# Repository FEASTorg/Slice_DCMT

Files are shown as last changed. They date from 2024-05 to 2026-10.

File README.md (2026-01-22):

# DC Motor Driver IC Carrier

DC Motor Driver IC Carrier Slice for BREAD.

## Introduction

[Short introduction on the project.]

## Usage

[Explain how to use the project. Include examples and screenshots if applicable.]

## Documentation

Please refer to the [docs](/docs) for more info.

---

<div align="center">
  <p>
    
    
  </p>
</div>

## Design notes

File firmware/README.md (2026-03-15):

# DCMT Firmware Profiles

This firmware separates three concerns:

1. Hardware generation (`DCMT_HW_GEN`)
- selects pin/electrical mapping only.

2. MCU performance profile
- derived from board target by default.
- classic Nano (AVR): speed loop disabled by default.
- Nano Every (megaAVR): speed loop enabled by default.

3. I2C address (`I2C_ADR`)
- independent from generation and board.
- override with `-DI2C_ADR=<addr>`.

## Environment Matrix

- `gen1_nano`
- `gen2_nano`
- `gen1_nanoevery`
- `gen2_nanoevery`

All environments support:

- open-loop
- closed-loop position

Speed closed-loop is controlled by `DCMT_ENABLE_SPEED_LOOP`.
Default behavior is board-dependent (see above), and can be overridden via build flag.

## Closed-Loop Backend

The runtime uses:

- `DCMotorServo` for closed-loop position control
- `DCMotorTacho` for cascaded closed-loop speed control

Current defaults mirror archive-proven values:

- `MOTOR1_CPR = 798`
- `MOTOR2_CPR = 798`
- outer PID defaults: `0.15 / 0.01 / 0.01`
- inner PID defaults: `0.15 / 0.01 / 0.01`
- servo PWM skip: `15`
- servo max PWM: `150`
- servo accuracy: `10`
- tacho interval: `5 ms`

Speed commands/capability are only available when `DCMT_ENABLE_SPEED_LOOP=1`.

## Capability Mapping (`GET_CAPS`)

- Level 2: baseline + closed-position + PID tuning
- Level 3: Level 2 + closed-speed

Controllers should gate behavior by capability flags, not by generation labels.

## References

- Arduino Nano: https://store.arduino.cc/products/arduino-nano
- Arduino Nano Every: https://store.arduino.cc/products/nano-every
- Nano Every docs: https://docs.arduino.cc/hardware/nano-every

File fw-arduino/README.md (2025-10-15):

# Firmware

This directory contains the firmware for the DC Motorized Translation (DCMT) stage. There are three versions of the firmware available:

1. **DCMT-old**: This is the original firmware version used in earlier iterations of the DCMT stage. It provides basic functionality for controlling the motorized stage.

2. **DCMT-open-control**: This version of the firmware allows for open-loop control of the DCMT stage. It provides improved performance and additional features compared to the old version.

3. **DCMT-closed-control**: This is the most advanced version of the firmware, offering closed-loop control for enhanced precision and reliability. It includes features such as position feedback and error correction.

## Development

Always ensure you update the version number in `config.h` when making changes to the firmware and update it's changelog. This helps in tracking different versions and ensuring compatibility with other components of the system.

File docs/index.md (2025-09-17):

---
title: "Slice DCMT Documentation"
description: "Overview and entry page for Slice DCMT project documentation."
nav_exclude: true
---

Welcome to the Slice DCMT project documentation.

## Board Renders

<figure style="display:inline-block; text-align:center; margin:10px;">
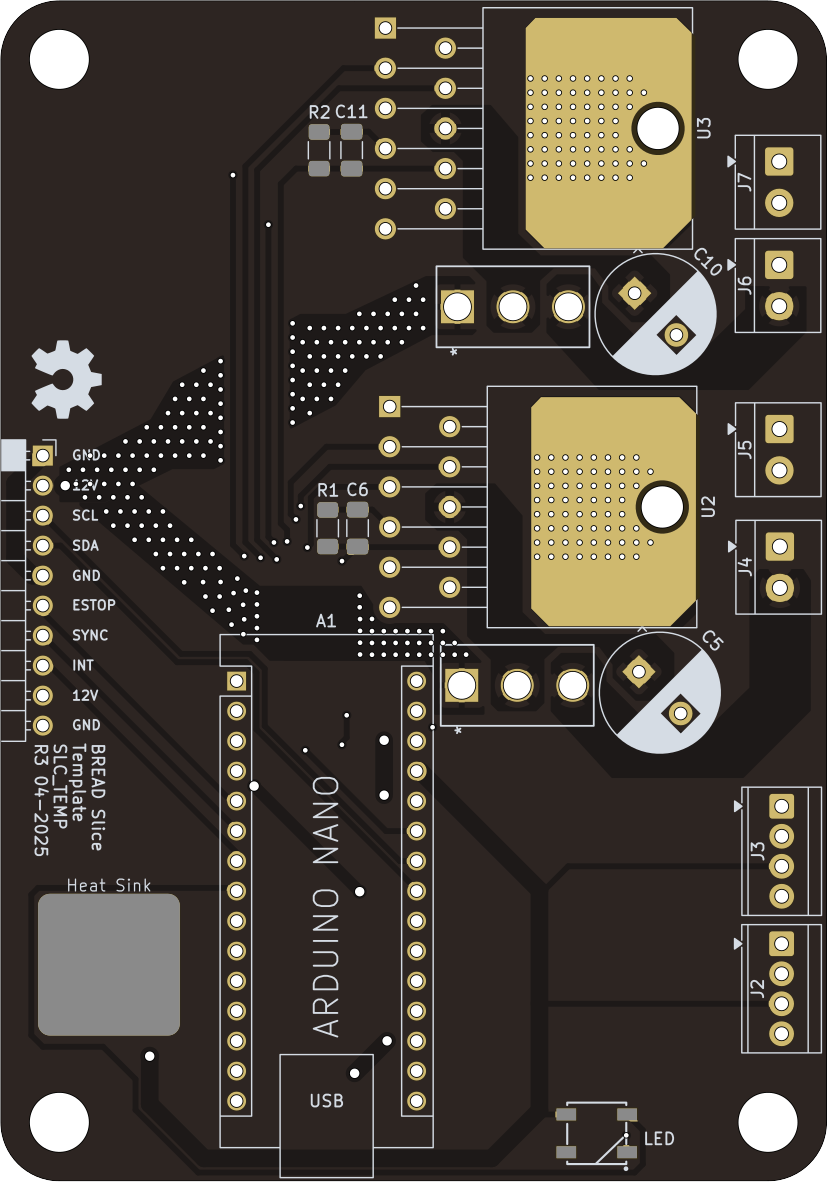
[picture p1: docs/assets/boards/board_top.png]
Board Top
  
  <figcaption>Top</figcaption>
</figure>

<figure style="display:inline-block; text-align:center; margin:10px;">
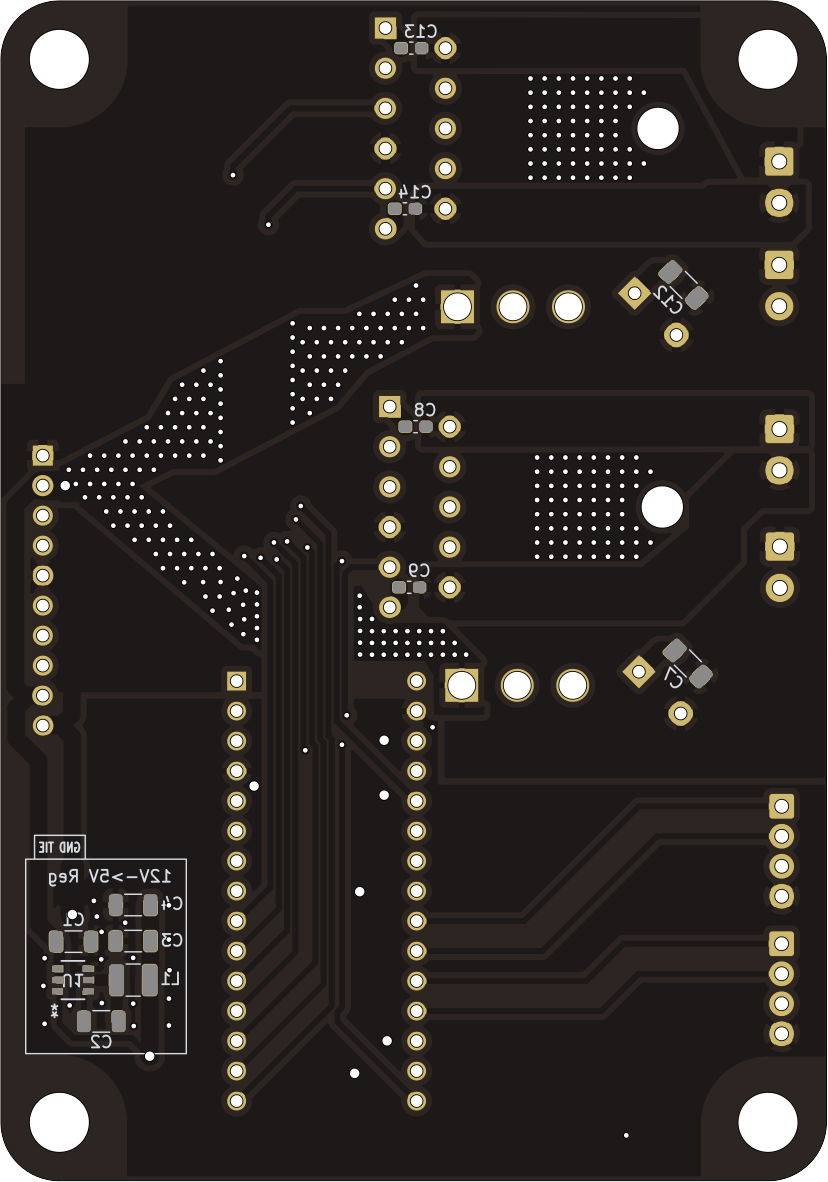
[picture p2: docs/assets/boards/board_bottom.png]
Board Bottom
  
  <figcaption>Bottom</figcaption>
</figure>

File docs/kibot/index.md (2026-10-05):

---
title: "KiBot Outputs"
description: "Index for KiBot-generated PCB artifacts."
layout: "page"
---

These are the docs & KiBot Outputs for Slice DCMT

The following files were generated from the latest PCB build:

- [Schematic.pdf](./Schematic.pdf)
- [PCB.pdf](./PCB.pdf)
- [kibot.log](./kibot.log)
- [BREAD_Slice-bom.html](./BREAD_Slice-bom.html)
- [BREAD_Slice-ibom.html](./BREAD_Slice-ibom.html)

_Last updated automatically on 2026-10-05 at 21:38:37 UTC by KiBot via GitHub Actions._

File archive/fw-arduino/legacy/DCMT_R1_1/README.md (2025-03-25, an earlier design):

# RLHT R1.1 Firmware Docs

Notes on the firmware for dc motor controller slice.

## Serial Command Usage

Send commands via serial using the following formats:

- **Mode Switch (`M` Command):**  
  Format: `M,<mode>`  
  Example: `M,0` (switches to CONTROL mode), `M,1` (switches to WRITE mode)

- **Motor Update (`W` Command):**  
  Format: `W,<motorSelect>,<speedSelect>`  
  Example: `W,1,100` (sets motor 1 speed to 100%), `W,2,-50` (sets motor 2 speed to 50% in reverse)

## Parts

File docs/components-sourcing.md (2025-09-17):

---
title: "Components Sourcing"
description: "Notes and vendor links for sourcing driver ICs and parts."
---

## Driver Options

- LMD18200
  - 3A, 55V H-Bridge
  - [Product page (LMD18200) — Texas Instruments](https://www.ti.com/product/LMD18200)
  - $23.14 (TO-220-11 Formed Leads) on [DigiKey](https://www.digikey.ca/en/products/detail/texas-instruments/LMD18200T-NOPB/148219)
- DRV8874
  - 40-V, 6-A H-bridge motor driver with integrated current sensing feedback
  - [Product page (DRV8874) — Texas Instruments](https://www.ti.com/product/DRV8874)
  - $2.42 (16-HTSSOP) on [DigiKey](https://www.digikey.ca/en/products/detail/texas-instruments/DRV8874PWPR/11502339)
- DRV8256
  - 50-V, 8-A H-bridge motor drivers with integrated current sense and smart tune technology
  - [Product page (DRV8256) — Texas Instruments](https://www.ti.com/product/DRV8256)
  - $3.50 (24-VQFN (4x4)) on [DigiKey](https://www.digikey.ca/en/products/detail/texas-instruments/DRV8256ERGER/13627083)
  - $3.81 (28-HTSSOP) on [DigiKey](https://www.digikey.ca/en/products/detail/texas-instruments/DRV8256EPWPR/15856968)
- DRV8873
  - 40-V, 10-A H-bridge motor driver with integrated current sensing & current sense feedback
  - [Product page (DRV8873) — Texas Instruments](https://www.ti.com/product/DRV8873)
  - $3.36 (24-HTSSOP (Hardwired)) on [DigiKey](https://www.digikey.ca/en/products/detail/texas-instruments/DRV8873HPWPR/9861442)
  - $3.62 (24-HTSSOP (SPI)) on [DigiKey](https://www.digikey.ca/en/products/detail/texas-instruments/DRV8873SPWPR/9861443)
- DRV8876
  - 40-V, 3.5-A H-bridge motor driver with integrated current sensing & current-sense feedback
  - [Product page (DRV8876) — Texas Instruments](https://www.ti.com/product/DRV8876)
  - $1.74 (16-VQFN (3x3)) on [DigiKey](https://www.digikey.ca/en/products/detail/texas-instruments/DRV8876RGTR/11308784)
  - $1.72 (16-HTSSOP) on [DigiKey](https://www.digikey.ca/en/products/detail/texas-instruments/DRV8876PWPR/10270191)
- DRV8251A
  - 50-V, 4.1-A H-bridge motor driver with integrated current regulation & current-sense feedback
  - [Product page (DRV8251A) — Texas Instruments](https://www.ti.com/product/DRV8251A)
  - $1.78 (8-PowerSOIC) on [DigiKey](https://www.digikey.ca/en/products/detail/texas-instruments/DRV8251ADDAR/16182453) (DRV8251ADDAR)
- DRV8231A
  - 35-V, 3.7-A H-bridge motor driver with integrated current regulation & current-sense feedback
  - [Product page (DRV8231A) — Texas Instruments](https://www.ti.com/product/DRV8231A)
  - $1.28 (8-WSON (2x2)) on [DigiKey](https://www.digikey.ca/en/products/detail/texas-instruments/DRV8231ADSGR/15853799)
  - $1.30 (8-PowerSOIC) on [DigiKey](https://www.digikey.ca/en/products/detail/texas-instruments/DRV8231ADDAR/16184255)

## Parts dump

- SPDT switches
  - 5 A: [e-switch 500SSP1S2M2QEA on DigiKey](https://www.digikey.ca/en/products/detail/e-switch/500SSP1S2M2QEA/1803993)
  - 6 A: [C&K 1101M2S3CQE2 on DigiKey](https://www.digikey.ca/en/products/detail/c-k/1101M2S3CQE2/67042)
- THT capacitors
  - 220 µF, 50 V aluminum electrolytic radial can, 42 mΩ @ 100 kHz, 4000 hrs @ 105 °C
  - [Kemet ESY227M050AH2AA on DigiKey](https://www.digikey.ca/en/products/detail/kemet/ESY227M050AH2AA/2712529)

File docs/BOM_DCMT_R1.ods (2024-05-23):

References | Value | Footprint | Quantity | URL
C6, C8, C9, C10, C11, C12 | 10 nF | C_1206_3216Metric_Pad1.33x1.80mm_HandSolder | 6 | https://www.digikey.ca/en/products/detail/walsin-technology-corporation/1206B103J500CT/9355096
C1, C5, C7 | 22uF | C_1206_3216Metric | 3 | https://www.digikey.ca/en/products/detail/samsung-electro-mechanics/CL31A226KAHNNNE/3888705
C2, C3 | 10uF_t | C_1206_3216Metric | 2 | https://www.digikey.ca/en/products/detail/yageo/cc1206kkx5r8bb106/2833631
C4 | 100nF | C_1206_3216Metric | 1 | https://www.digikey.ca/en/products/detail/samsung-electro-mechanics/CL31B104KBCNNNC/3886675
R1, R2 | 4.42 k | R_1206_3216Metric_Pad1.30x1.75mm_HandSolder | 2 | https://www.digikey.ca/en/products/detail/yageo/RC1206FR-074K42L/728878
L1 | 4.7uH | L_1210_3225Metric | 1 | https://www.digikey.ca/en/products/detail/tdk-corporation/BCL322520RT-4R7M-D/15849704
D2 | WS2812B_5050 | WS2812-5050-4PIN | 1 | https://www.digikey.ca/en/products/detail/sparkfun-electronics/COM-16347/11630204
U1, U3 | LMD18200 | TO-220-11_P3.4x5.08mm_StaggerOdd_Lead4.85mm_Vertical | 2 | https://www.digikey.ca/en/products/detail/texas-instruments/LMD18200T/3701191
U2 | AP63205WU-7 | TSOT-23-6 | 1 | https://www.digikey.ca/en/products/detail/diodes-incorporated/AP63205WU-7/9858424
SW1, SW2 | SW_SPDT | L102011MS02Q | 2 | https://www.digikey.ca/en/products/detail/c-k/L102011MS02Q/484143
A1 | Arduino_Nano_v3.x | Arduino_Nano | 1 | https://www.amazon.ca/ELEGOO-Arduino-ATmega328P-Without-Compatible/dp/B0713XK923
HS1 | Heatsink_Pad (optional) | Thermal Pad | 1 | https://www.digikey.ca/en/products/detail/assmann-wsw-components/V2017B/3511410
J10, J11, J13, J15, J16, J17 | Term_PressFit_Phoenix_Contact | Term_PressFit_5mm_H_PC | 2 (4x) | https://www.digikey.ca/en/products/detail/phoenix-contact/1990999/3605138
J12, J14 | Term_PressFit_Phoenix_Contact | Term_PressFit_5mm_H_ENDCAP_PC
J2, J3, J4, J5, J7, J8, J9 | Term_PressFit_Phoenix_Contact | Term_PressFit_3.5mm_H_PC | 1 (8x) | https://www.digikey.ca/en/products/detail/phoenix-contact/1990795/3605145
J6 | Term_PressFit_Phoenix_Contact | Term_PressFit_3.5mm_H_ENDCAP_PC | 1
J1 | Conn_01x10_Female | PinSocket_1x10_P2.54mm_Horizontal | 1 | https://www.digikey.ca/en/products/detail/sullins-connector-solutions/PPTC101LGBN-RC/775904
J18 | I2C_01x04 | JST_SH_SM04B-SRSS-TB_1x04-1MP_P1.00mm_Horizontal | 1 | https://www.digikey.ca/en/products/detail/jst-sales-america-inc/SM04B-SRSS-TB/926710

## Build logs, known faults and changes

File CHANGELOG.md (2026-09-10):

# Changelog

All notable changes to Slice DCMT are documented here.

This project did not use formal release tags through most of its history, so this changelog is organized by dated development eras rather than semantic-version releases.

## [Unreleased]

### Fixed

- **The Docs Pipeline runs again.** `hardware/.history` was committed as a
  gitlink (mode `160000`) with no `.gitmodules` entry, so `actions/checkout`
  failed with `fatal: No url found for submodule path 'hardware/.history'`
  and all three KiBot jobs — Fab, ERC and DRC — died before running, taking
  the index and Pages deploy with them. The directory is KiCad 10's own
  Local History: KiCad runs `git_repository_init` on `<project>/.history`,
  so committing it records a gitlink to a repository this one knows nothing
  about. It is recreated on every project open, on every machine, which is
  why the ignore rule matters rather than a one-time cleanup.

- **Corrected the G1 pin map in `docs/hardware-revisions.md`.** D8 and D12
  were listed as unused; G1 routes `/THRM2` to D8 and `/THRM1` to D12, on
  Nano pads 11 and 15. D13 is the unused one. The whole table has since been
  regenerated from the board files. No firmware impact — the thermal flags
  are not read anywhere in `firmware/`.

- **The status LED no longer drives motor 1's direction line on gen1** (#15).
  `LED_PIN` sits in the shared "General BREAD" block and is inherited by every
  slice whether or not that board populates an LED — `Slice_RLHT` carries the
  identical line. Gen1 DCMT boards do not populate it, and gen1 additionally maps
  `MOTOR1_DIR` to the same MCU pin (5), so FastLED's NeoPixel bit-banging wrote
  onto motor 1's direction line. Motor 1 is the sample pump on `dcmt0` and a
  dosing pump on `dcmt1`; the impeller is motor 2 and is unaffected.

  `Slice_RLHT` encoded the same fact as `RLHT_HAS_STATUS_LED` when the gen1/gen2
  split was done (2026-03-09); DCMT's split landed the same day without it. This
  adds the mirror-image `DCMT_HAS_STATUS_LED`.

  The worst case was the e-stop path rather than boot. `LMD18200::brake()` never
  touches DIR and is idempotent, and a held e-stop or watchdog trip calls only
  `brake()` — so a direction bit scrambled by `FastLED.show()` during an e-stop
  **persisted until the next `write()`**, rather than being corrected on the next
  control cycle. (At boot the LED write is overwritten microseconds later by
  `motor1Driver.begin()`/`write(0)`, so the boot case was benign.)

  `LED_PIN` itself is now defined only on boards that have the LED, so a future
  call site that reaches for it on gen1 is a build failure rather than a silent
  repeat of this bug.

  **Gen1 boards no longer have a local e-stop indicator.** The red/green LED was
  the only unconditional at-the-bench signal; `SLICE_DEBUG` serial output is
  compiled out by default. E-stop state remains readable over the bus via
  `reply_get_state`.

### Added

- Added a curated root changelog derived from the full repository and history review.

### Changed

- **Archived board directories now name their generation**:
  `archive/hw_archive/g1-2021-06-08-mtu/` and
  `archive/hw_archive/g2-2024-02-13-finn/`. The dates are the boards' own;
  the G2 one is marked on the JLC silkscreen. Directory names were the only
  record of which archived project was which generation, and they did not
  say, which is what made a G1 board in service look like the board in
  `hardware/`.

- **Removed the redundant second G1 archive** (`archive/hw_archive/2023-12-13/`).
  Converting both projects to a common format showed it was a KiCad 6
  re-save rather than a second fabrication run: identical pad-to-net map
  (112 pads), identical copper geometry (198 tracks, arcs and vias) and a
  byte-identical exported netlist. Recoverable from git history.

- Updated active firmware metadata to reference CRUMBS `0.12.4` and
  `bread-crumbs-contracts` `0.4.3`.

### Fixed

- Fixed intermittent CRUMBS query failures (all-`0xFF` non-responses and
  CRC-corrupt replies, ~1-47% of reads from a Raspberry Pi master) caused by
  the whole-struct interrupt-masked snapshot in `motorControlLogic()`
  introduced by the 2026-05-12 shared-state hardening. The ~72-byte copy
  masked interrupts for ~20-36 µs every loop iteration, delaying TWI ISR
  entry at the SLA+R boundary; the resulting clock stretch is mishandled by
  the Pi's I2C controller. The snapshot now copies only the scalar control
  inputs in a short window, with PID tunings fetched separately only in
  closed-loop modes. Verified on hardware: 0/1050 failed queries versus
  26/1050 on a same-bus stock control board. (#3)

## [2026-05-12] Firmware Runtime Hardening

### Added

- Added a 1 second AVR watchdog to the active PlatformIO firmware.

### Changed

- Reworked shared state access so firmware snapshots and commits are protected with interrupt guards.
- Replaced Arduino `String`-based serial command parsing with a fixed static command buffer.

### Fixed

- Fixed serial command trimming so empty strings are handled safely.
- Added portability fixes for megaAVR/Nano Every targets.
- Reduced runtime heap-fragmentation risk in serial command handling.

## [2026-04-01 to 2026-04-20] Dependency And Organization Cleanup

### Changed

- Bumped active firmware dependencies to CRUMBS `0.12.0` and `bread-crumbs-contracts` `0.4.1`.
- Updated repository, docs, and workflow references from `FEASTorg` casing to `feastorg`.
- Refreshed generated KiBot documentation output after the organization rename.

## [2026-03-08 to 2026-03-18] PlatformIO Firmware Modernization

### Added

- Added active PlatformIO build environments for `gen1_nano`, `gen2_nano`, `gen1_nanoevery`, and `gen2_nanoevery`.
- Added Nano Every support with board-dependent speed-loop defaults.
- Added optional closed-loop speed support through `DCMotorTacho` for capable builds.
- Added closed-loop position support through `DCMotorServo`.
- Added bitwise capability replies for baseline, closed-position, PID tuning, and optional closed-speed support.
- Added build-flag controlled I2C address selection.
- Added build-flag controlled CRUMBS/debug output.
- Added archive preservation for the former Arduino and PlatformIO firmware generations.
- Added `.gitattributes` for cross-platform file normalization.

### Changed

- Converted active firmware to newer CRUMBS and published BREAD/DCMT contracts.
- Moved active firmware away from vendored CRUMBS and LMD18200 code toward published package dependencies.
- Separated hardware generation, MCU target/profile, control capability, and I2C address selection.
- Made setpoints and PID tunings preloadable independent of the active control mode.
- Made module version ownership come from the published contract rather than a duplicate local definition.
- Reworked CRUMBS state replies to use a fixed payload layout across modes.
- Reorganized active and archived firmware directories.

### Fixed

- Restored proper closed-loop position behavior through the DCMotorServo backend.
- Improved e-stop handling with debounce and internal pull-up input behavior.
- Prevented repeated PID reapplication when tuning values have not changed.
- Removed setpoint gating that prevented controllers from preloading values.
- Added explicit invalid-data sentinels for unsupported or inactive state fields.
- Inset encoder range reporting to avoid false sentinel-value collisions.
- Fixed servo function declaration ordering.
- Reduced serial string-handling fragility.

## [2026-01-22 to 2026-02-01] Legacy Firmware Organization And Template Review

### Added

- Added older generation firmware scripts for historical context.

### Changed

- Reorganized firmware layout before the March 2026 active firmware rewrite.
- Reviewed and revised the repo against the current project template and KMLib-era conventions.
- Refreshed generated KiBot index and board render outputs through CI reruns.

## [2025-10-15 to 2025-10-22] Firmware Versioning And Split

### Added

- Added explicit firmware versioning.
- Added changelog files for generation-specific Arduino firmware snapshots.

### Changed

- Updated firmware for different board revisions.
- Updated uploaded/default address tracking.
- Renamed firmware folders/files to better match hardware revisions.
- Split firmware organization into Arduino and PlatformIO tracks.

## [2025-09-05 to 2025-09-24] Docs, KiBot, And GitHub Pages Automation

### Added

- Added GitHub Actions automation to build KiBot outputs and publish them to GitHub Pages.
- Added a docs site structure with index, component sourcing, architecture, testing, changelog, TODO, and KiBot output pages.
- Added KiBot output indexing for generated artifacts.
- Added top and bottom PCB render assets for the docs site.
- Added interactive HTML BOM publishing.
- Added KiBot 3D model caching and retry behavior for more reliable CI runs.

### Changed

- Switched docs to Just the Docs/Jekyll configuration.
- Moved KiBot site configuration under `docs/kibot/`.
- Centralized hardware/docs publishing through reusable infrastructure workflows, first under `slice-infra` and then under `bread-infra`.
- Renamed workflow roles toward the current `docs-pipeline` and `publish-kibot` flow.
- Moved component sourcing notes into their own document.

### Fixed

- Fixed Pages deployment ordering so published pages align with the generated KiBot index commit.
- Fixed artifact download, staging, push/rebase, and generated-index behavior across the docs pipeline.
- Fixed Jekyll/front matter issues that affected navigation and page rendering.
- Fixed iBoM and artifact glob handling so all matching KiBot outputs are published.
- Fixed PCB render generation, including true bottom-view rendering.
- Removed brittle yq handling in favor of native Python parsing in the automation path.
- Cleaned up temporary debug and generated-index workflow churn after the pipeline stabilized.

## [2025-05-06 to 2025-05-19] Hardware Revision And First KiBot Workflow

### Added

- Added the main current KiCad hardware source under `hardware/`.
- Added `motor_driver_lmd18500.kicad_sch` for the motor driver sheet.
- Added KiBot configuration for schematic PDF, PCB PDF, BOM, iBoM, Gerbers, drill files, position files, and board renders.
- Added a hardware Makefile with KiBot targets for ERC, DRC, schematic fabrication output, and PCB fabrication output.
- Added early GitHub Actions workflow support for KiBot runs.
- Added notes for alternative future motor-driver parts.

### Changed

- Consolidated newer hardware work from temporary/new folders into the primary `hardware/` directory.
- Moved historical hardware snapshots into archive locations.
- Updated the PCB around electrolytic capacitance, filled zones, thermal/tab layout, and 12 V routing constraints.
- Moved the KiBot config under `hardware/`.

### Fixed

- Corrected initial KiBot workflow naming, paths, root references, Makefile location, and config placement.

## [2025-02-20 to 2025-04-19] Hardware Archive And Firmware Control Expansion

### Added

- Added historical PCB snapshots from 2021 and 2023.
- Added braking support to the firmware lineage.
- Added newer DCMT firmware sketches and preserved older sketches under legacy paths.
- Added LMD18200 library usage to the firmware.
- Added DCMT-specific request/message handlers, serial commands, and serial output helpers.
- Added early position and speed controller support.
- Added a new hardware design branch before it was later consolidated into the main hardware folder.

### Changed

- Reorganized firmware into active and legacy sketch directories.
- Renamed RLHT-oriented handler naming to DCMT-specific naming.
- Evolved firmware from basic motor output toward position/speed control behavior.

### Fixed

- Removed temporary KiCad autosave and lock artifacts that were introduced during early hardware editing.

## [2024-05-23 to 2024-09-10] Project Foundation

### Added

- Added the initial KiCad hardware project for the DC Motor Driver IC Carrier Slice.
- Added the initial license, `.gitignore`, README, BOM material, and generated fabrication outputs.
- Added `BOM_DCMT_R1.ods` as the early BOM artifact.
- Added the first firmware seed sketch under `firmware/`.

### Changed

- Refreshed the initial KiCad board and schematic after the first repository seed.
- Simplified the README as the repo shifted from hardware-only scaffolding toward a combined hardware/firmware project.

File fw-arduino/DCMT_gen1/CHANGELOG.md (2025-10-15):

# DCMT (Old) Changelog

## Version 1.0.0

- Initial release of the DCMT (Old) firmware.

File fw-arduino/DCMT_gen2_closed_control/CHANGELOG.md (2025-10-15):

# DCMT Closed Control Changelog

## Version 1.0.0

- Initial release of the DCMT Closed Control firmware.

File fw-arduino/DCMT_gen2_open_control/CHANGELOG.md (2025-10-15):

# DCMT Open Control Changelog

## Version 1.0.0

- Initial release of the DCMT Open Control firmware.

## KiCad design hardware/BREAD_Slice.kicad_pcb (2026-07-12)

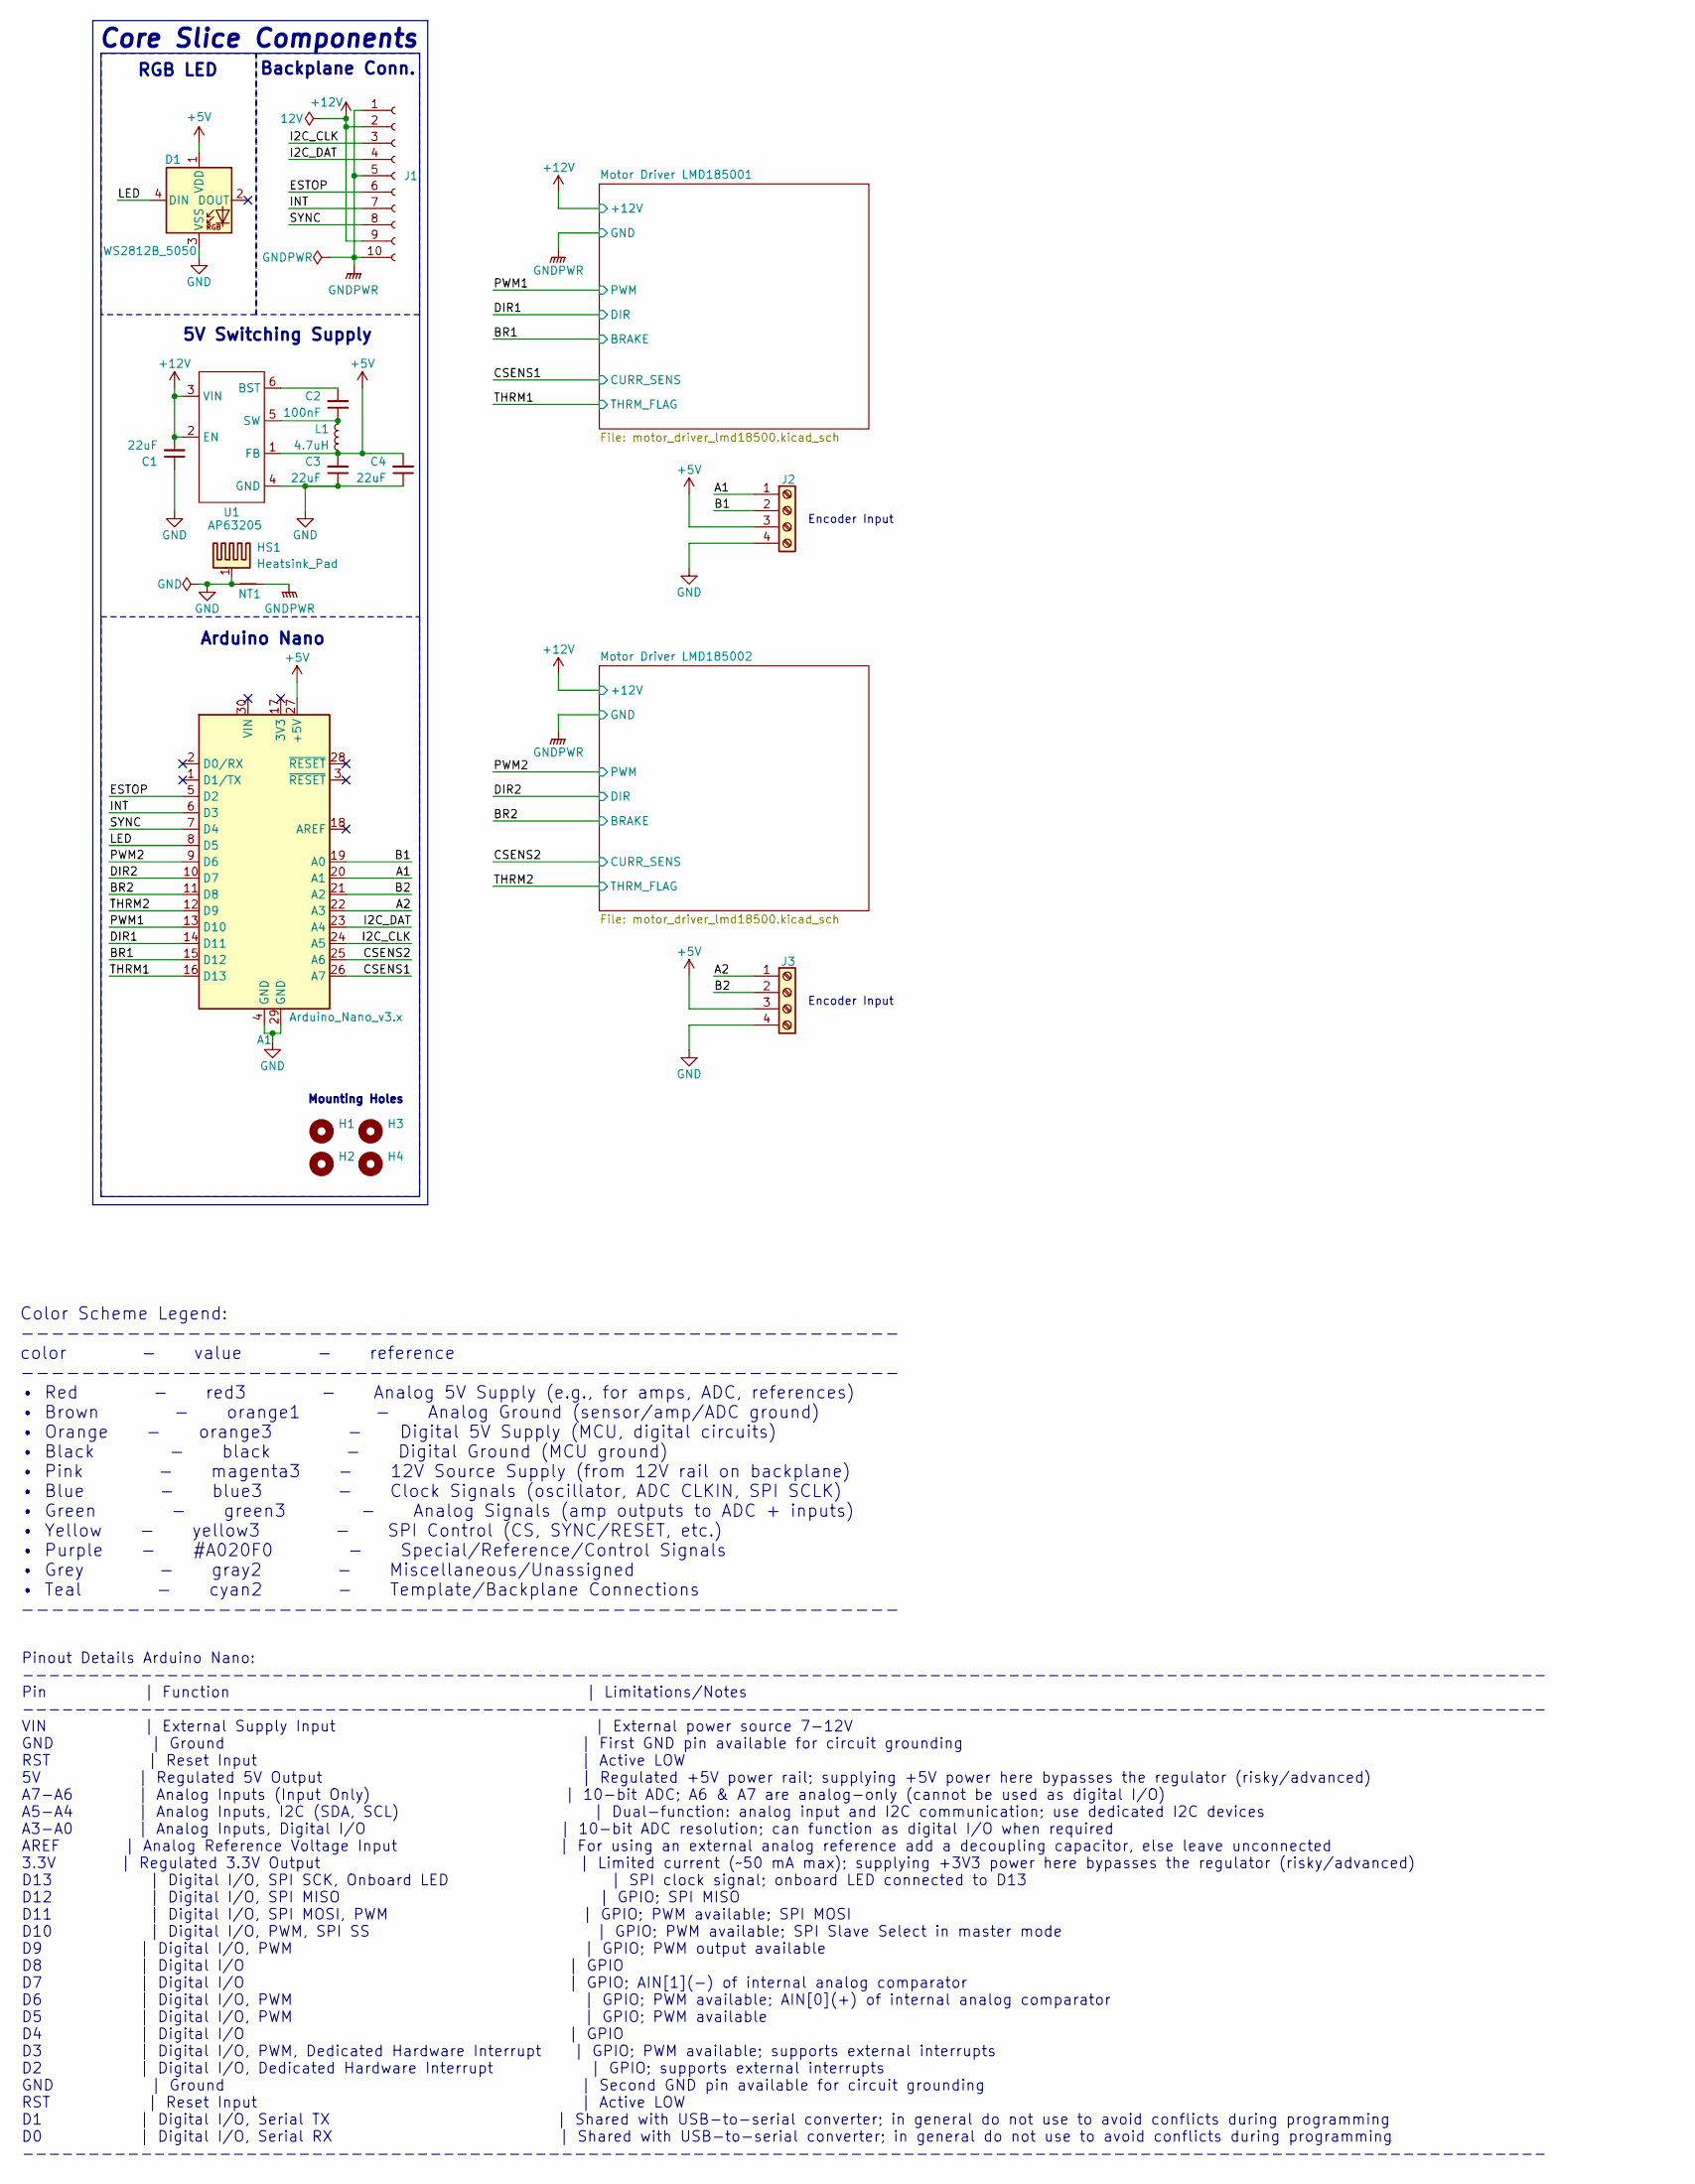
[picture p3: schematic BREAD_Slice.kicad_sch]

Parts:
A1: Arduino_Nano_v3.x; Arduino_Nano
C1, C3, C4: 22uF; C_1206_3216Metric
C2: 100nF; C_1206_3216Metric
D1: WS2812B_5050; WS2812-5050-4PIN
H1, H2, H3, H4: MountingHole; MountingHole_5mm
HS1: Heatsink_Pad; Thermal_Pad
J1: Conn_01x10_Socket; PinSocket_1x10_P2.54mm_Horizontal
J2, J3: Screw_Terminal_01x04; TerminalBlock_TE_282834-4_1x04_P2.54mm_Horizontal
L1: 4.7uH; L_1210_3225Metric
NT1: NetTie_2; NetTie-2_SMD_Pad2.0mm
U1: AP63205; SOIC_05WU-7_DIO

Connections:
+5V: A1.27 (+5V), C3.2, C4.2, D1.1 (VDD), J2.3, J3.3, L1.2, U1.1 (FB)
+12V: C1.2, J1.2, J1.9, U1.2 (EN), U1.3 (VIN); also elsewhere on the board
/A1: A1.20 (A1), J2.1
/A2: A1.22 (A3), J3.1
/B1: A1.19 (A0), J2.2
/B2: A1.21 (A2), J3.2
/BR1: A1.15 (D12); also elsewhere on the board
/BR2: A1.11 (D8); also elsewhere on the board
/CSENS1: A1.26 (A7); also elsewhere on the board
/CSENS2: A1.25 (A6); also elsewhere on the board
/DIR1: A1.14 (D11); also elsewhere on the board
/DIR2: A1.10 (D7); also elsewhere on the board
/ESTOP: A1.5 (D2), J1.6
/I2C_CLK: A1.24 (A5), J1.3
/I2C_DAT: A1.23 (A4), J1.4
/INT: A1.6 (D3), J1.7
/LED: A1.8 (D5), D1.4 (DIN)
/PWM1: A1.13 (D10); also elsewhere on the board
/PWM2: A1.9 (D6); also elsewhere on the board
/SYNC: A1.7 (D4), J1.8
/THRM1: A1.16 (D13); also elsewhere on the board
/THRM2: A1.12 (D9); also elsewhere on the board
GND: A1.4 (GND), A1.29 (GND), C1.1, C3.1, C4.1, D1.3 (VSS), HS1.1, J2.4, J3.4, NT1.1, U1.4 (GND)
GNDPWR: J1.1, J1.5, J1.10, NT1.2; also elsewhere on the board
unnamed: C2.2, U1.6 (BST)
unnamed: C2.1, L1.1, U1.5 (SW)

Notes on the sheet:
5V Switching Supply
Pinout Details Arduino Nano: -------------------------------------------------------------------------------------------------------------------- Pin | Function | Limitations/Notes -------------------------------------------------------------------------------------------------------------------- V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
RGB LED
Encoder Input
Color Scheme Legend: ---------------------------------------------------------- color - value - reference ---------------------------------------------------------- • Red - red3 - Analog 5V Supply (e.g., for amps, ADC, references) • Brown - orange1 - Analog Ground (sensor/amp/ADC ground) • Orange -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
Core Slice Components
Arduino Nano
Mounting Holes
Backplane Conn.

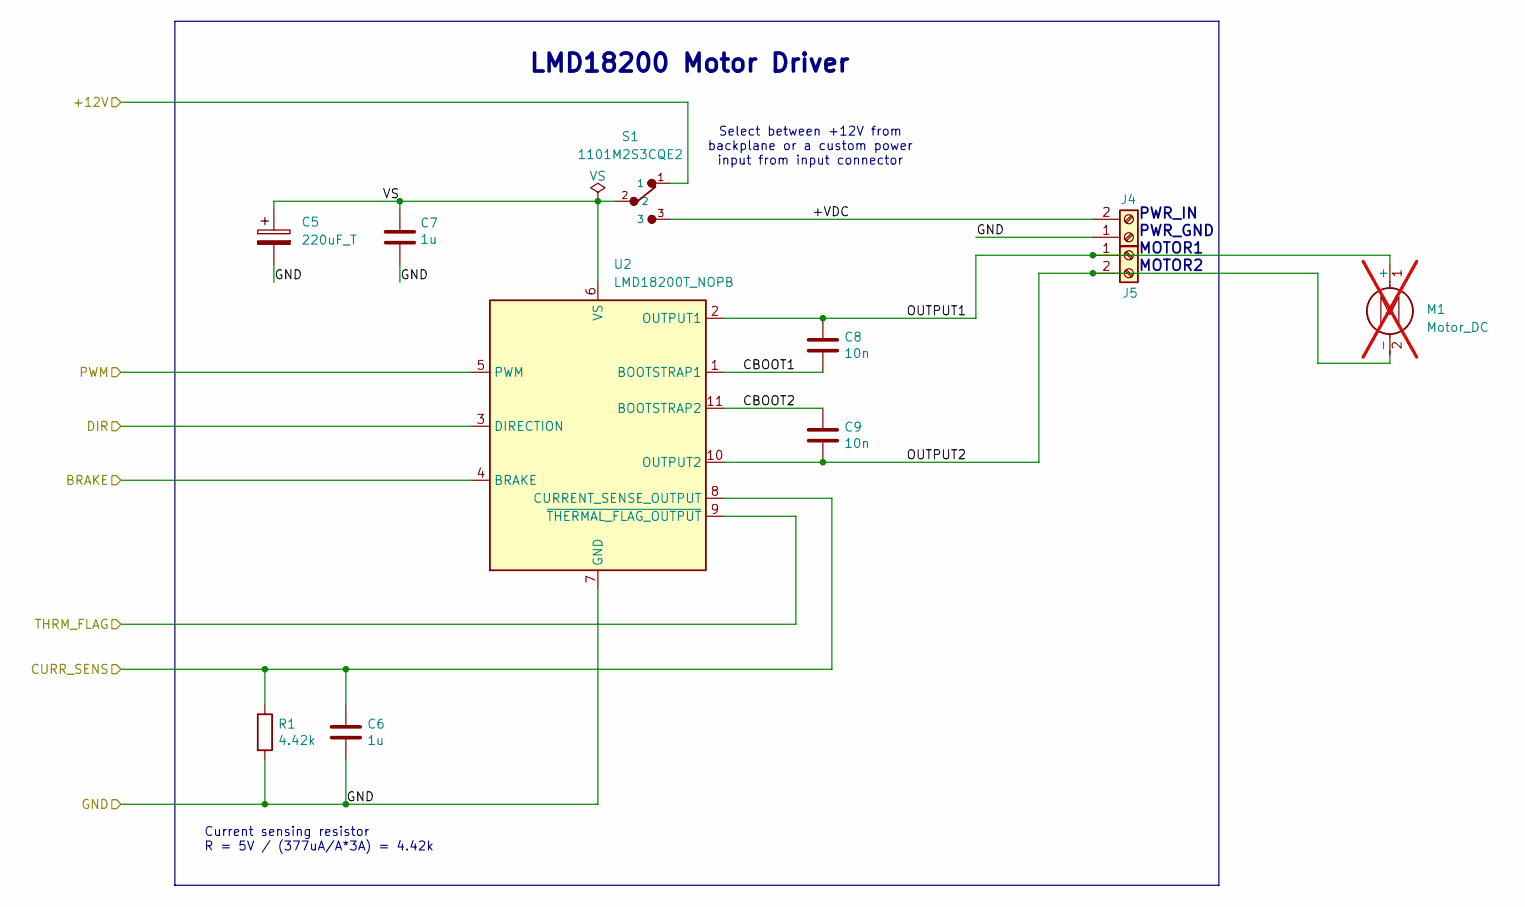
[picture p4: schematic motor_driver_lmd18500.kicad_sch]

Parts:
C5: 220uF_T; CP_Radial_D10.0mm_P5.00mm
C6, C7: 1u; C_1206_3216Metric_Pad1.33x1.80mm_HandSolder
C8, C9: 10n; C_0603_1608Metric_Pad1.08x0.95mm_HandSolder
J4, J5: Screw_Terminal_01x02; TerminalBlock_4Ucon_1x02_P3.50mm_Horizontal
M1: Motor_DC; not fitted
R1: 4.42k; R_1206_3216Metric_Pad1.30x1.75mm_HandSolder
S1: 1101M2S3CQE2; SW_Slide-CK-1101M2S3CQE2
U2: LMD18200T_NOPB; TO-220-11_P3.4x5.08mm_StaggerOdd_Lead8.45mm_TabDown

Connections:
+12V: S1.1; also elsewhere on the board
/BR1: U2.4 (BRAKE); also elsewhere on the board
/CSENS1: C6.1, R1.1, U2.8 (CURRENT_SENSE_OUTPUT); also elsewhere on the board
/DIR1: U2.3 (DIRECTION); also elsewhere on the board
/Motor Driver LMD185001/+VDC: J4.2, S1.3
/Motor Driver LMD185001/CBOOT1: C8.2, U2.1 (BOOTSTRAP1)
/Motor Driver LMD185001/CBOOT2: C9.1, U2.11 (BOOTSTRAP2)
/Motor Driver LMD185001/OUTPUT1: C8.1, J5.1, U2.2 (OUTPUT1)
/Motor Driver LMD185001/OUTPUT2: C9.2, J5.2, U2.10 (OUTPUT2)
/Motor Driver LMD185001/VS: C5.1, C7.1, S1.2, U2.6 (VS)
/PWM1: U2.5 (PWM); also elsewhere on the board
/THRM1: U2.9 (~THERMAL_FLAG_OUTPUT); also elsewhere on the board
GNDPWR: C5.2, C6.2, C7.2, J4.1, R1.2, U2.7 (GND); also elsewhere on the board

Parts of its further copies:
C10: 220uF_T; CP_Radial_D10.0mm_P5.00mm
C11, C12: 1u; C_1206_3216Metric_Pad1.33x1.80mm_HandSolder
C13, C14: 10n; C_0603_1608Metric_Pad1.08x0.95mm_HandSolder
J6, J7: Screw_Terminal_01x02; TerminalBlock_4Ucon_1x02_P3.50mm_Horizontal
R2: 4.42k; R_1206_3216Metric_Pad1.30x1.75mm_HandSolder
S2: 1101M2S3CQE2; SW_Slide-CK-1101M2S3CQE2
U3: LMD18200T_NOPB; TO-220-11_P3.4x5.08mm_StaggerOdd_Lead8.45mm_TabDown

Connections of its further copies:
+12V: S2.1; also elsewhere on the board
/BR2: U3.4 (BRAKE); also elsewhere on the board
/CSENS2: C11.1, R2.1, U3.8 (CURRENT_SENSE_OUTPUT); also elsewhere on the board
/DIR2: U3.3 (DIRECTION); also elsewhere on the board
/Motor Driver LMD185002/+VDC: J6.2, S2.3
/Motor Driver LMD185002/CBOOT1: C13.2, U3.1 (BOOTSTRAP1)
/Motor Driver LMD185002/CBOOT2: C14.1, U3.11 (BOOTSTRAP2)
/Motor Driver LMD185002/OUTPUT1: C13.1, J7.1, U3.2 (OUTPUT1)
/Motor Driver LMD185002/OUTPUT2: C14.2, J7.2, U3.10 (OUTPUT2)
/Motor Driver LMD185002/VS: C10.1, C12.1, S2.2, U3.6 (VS)
/PWM2: U3.5 (PWM); also elsewhere on the board
/THRM2: U3.9 (~THERMAL_FLAG_OUTPUT); also elsewhere on the board
GNDPWR: C10.2, C11.2, C12.2, J6.1, R2.2, U3.7 (GND); also elsewhere on the board

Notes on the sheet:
Select between +12V from backplane or a custom power input from input connector
Current sensing resistor R = 5V / (377uA/A*3A) = 4.42k
PWR_IN PWR_GND MOTOR1 MOTOR2
LMD18200 Motor Driver

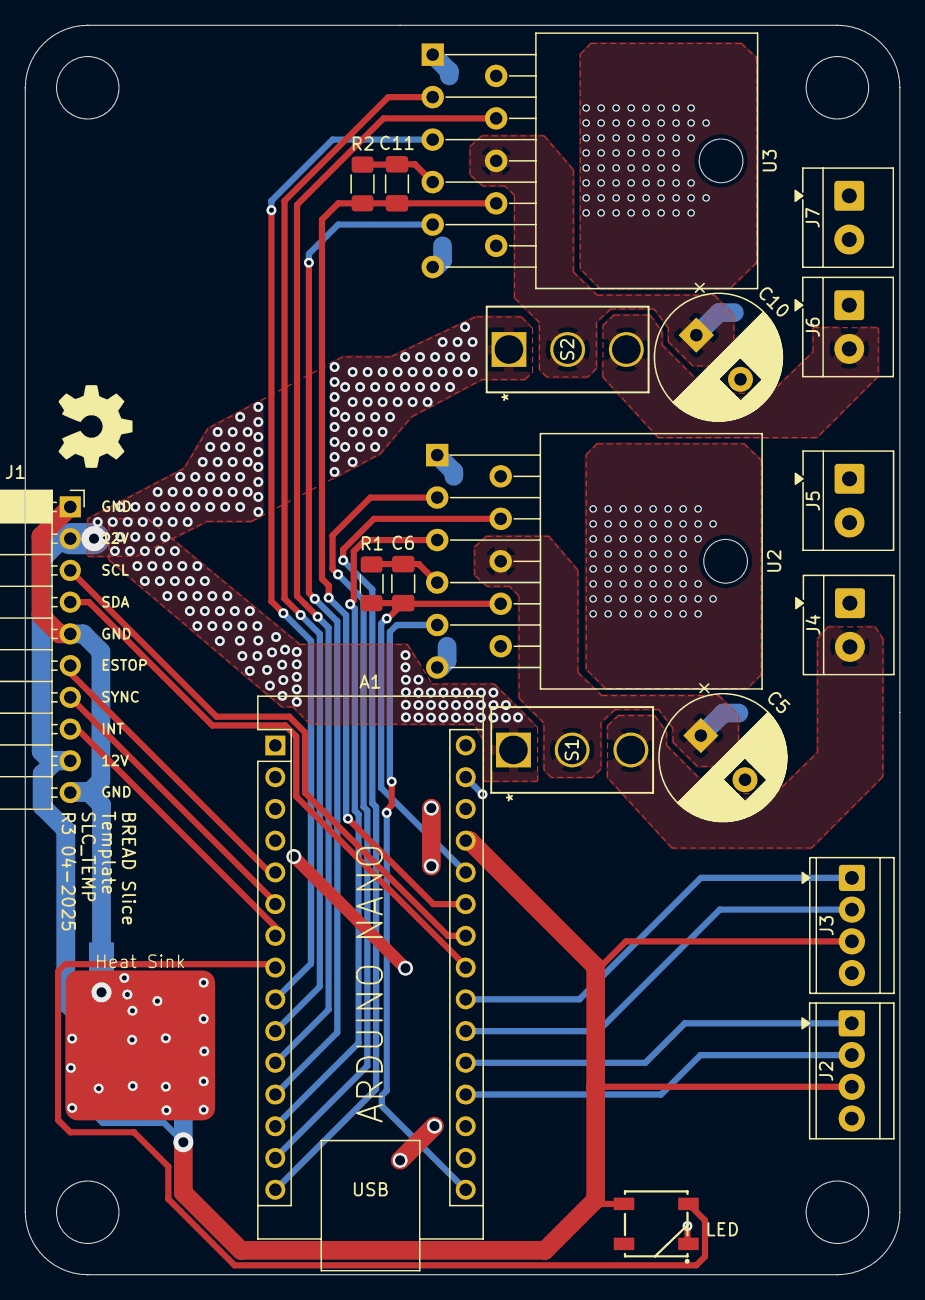
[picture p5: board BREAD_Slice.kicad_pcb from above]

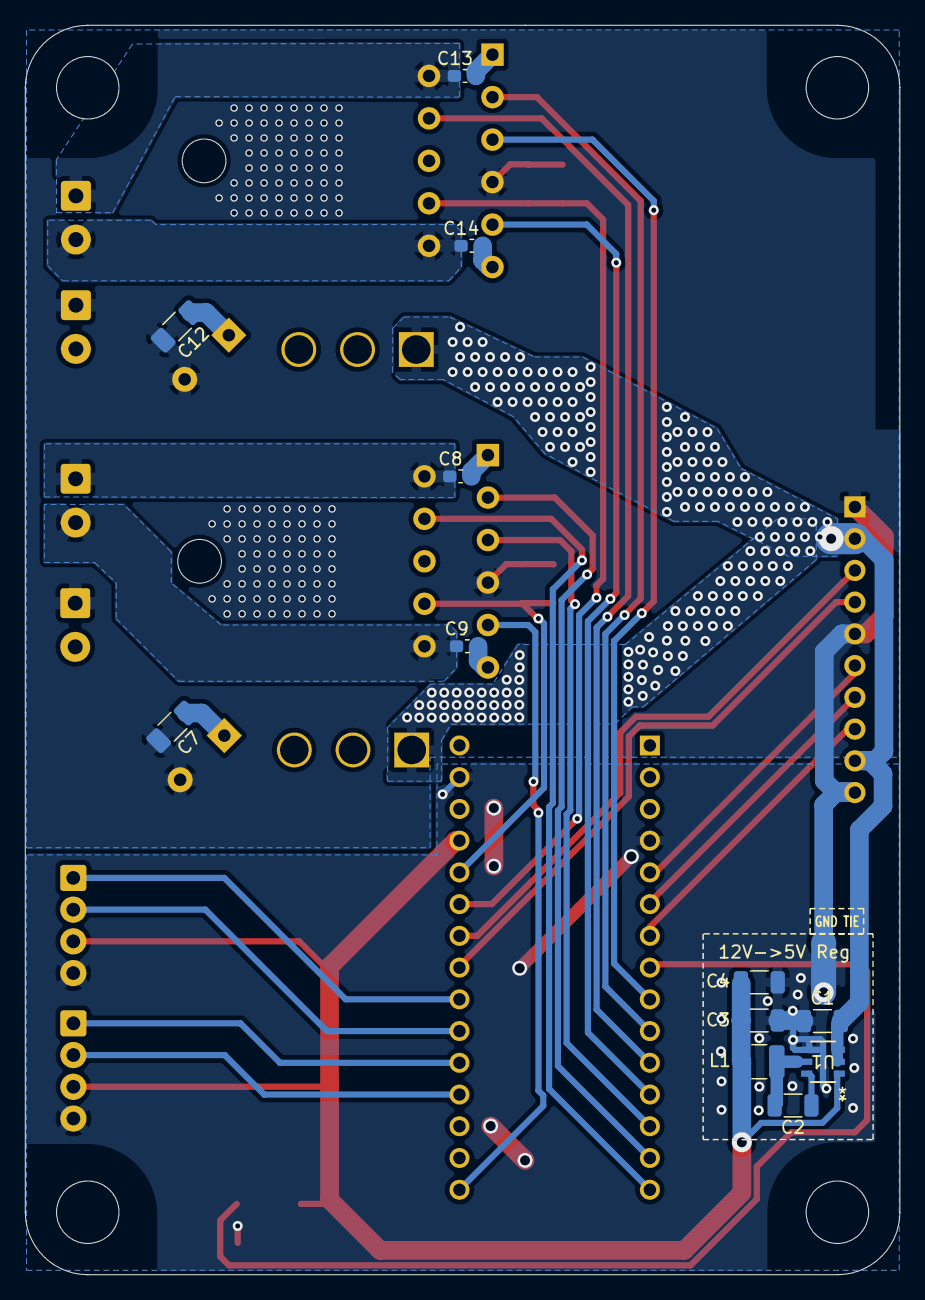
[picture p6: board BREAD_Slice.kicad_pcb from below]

Board: 2 copper layers, 70.0 x 100.0 mm, 38 parts (13 on the bottom side), 38 nets.

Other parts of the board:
Logo1: Logo_Open_Hardware_Small; OSHW-Symbol_6.7x6mm_SilkScreen

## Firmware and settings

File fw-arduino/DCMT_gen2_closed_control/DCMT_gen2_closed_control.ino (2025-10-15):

/**
 * @file DCMT.ino
 * @brief DCMT firmware for the BREAD system.
 * @author Cameron K. Brooks 2025
 *
 */

// DCMT specific libraries
#include <LMD18200.h>     // LMD18200 motor driver library
#include <Encoder.h>      // Encoder library for reading motor position
#include <DCMotorServo.h> // library using PID and encoder feedback for DC motor control
#include <DCMotorTacho.h> // library using PID and tachometer feedback for DC motor control

// shared BREAD libs
#include <FastLED.h>

// BREAD specific libs
#include <CRUMBS.h>

// sketch specific libs
#include "config_hardware.h" // hardware configuration containing pin definitions
#include "config.h"          // configuration file for constants such as i2c address and timing

// CRUMBS start
CRUMBS crumbsSlice(false, I2C_ADR); // Peripheral mode, I2C address 0x08

// flag for emergency stop
volatile bool estopTriggered = false;

// create object for the LED
CRGB led;

// Create first instance of the LMD18200 motor driver.
LMD18200 motor1Driver(MOTOR1_PWM_PIN, MOTOR1_DIR_PIN, MOTOR1_BRAKE_PIN, MOTOR1_CSENSE_PIN, MOTOR1_THERMAL_PIN);
// Create second instance of the LMD18200 motor driver.
LMD18200 motor2Driver(MOTOR2_PWM_PIN, MOTOR2_DIR_PIN, MOTOR2_BRAKE_PIN, MOTOR2_CSENSE_PIN, MOTOR2_THERMAL_PIN);

// Create first instance of the encoder.
Encoder motor1Encoder(MOTOR1_ENCODER_PIN1, MOTOR1_ENCODER_PIN2);
// Create second instance of the encoder.
Encoder motor2Encoder(MOTOR2_ENCODER_PIN1, MOTOR2_ENCODER_PIN2);

// Wrapper functions for the first motor driver and encoder.
void lmdMotor1Write(int16_t speed)
{
    motor1Driver.write(speed);
}
void lmdMotor1Brake()
{
    motor1Driver.brake();
}
long encoder1ReadFunc()
{
    return motor1Encoder.read();
}
void encoder1WriteFunc(long newPosition)
{
    motor1Encoder.write(newPosition);
}

// Wrapper functions for the second motor driver and encoder.
void lmdMotor2Write(int16_t speed)
{
    motor2Driver.write(speed);
}
void lmdMotor2Brake()
{
    motor2Driver.brake();
}
long encoder2ReadFunc()
{
    return motor2Encoder.read();
}
void encoder2WriteFunc(long newPosition)
{
    motor2Encoder.write(newPosition);
}

#define MOTOR1_PWM_SKIP 15 // PWM skip for motor 1
#define MOTOR1_PWM_MAX 150 // Max PWM for motor 1
#define MOTOR1_ACCURACY 10 // Accuracy for motor 1
DCMotorServo servo1(lmdMotor1Write, lmdMotor1Brake, encoder1ReadFunc, encoder1WriteFunc);

#define MOTOR2_PWM_SKIP 15 // PWM skip for motor 2
#define MOTOR2_PWM_MAX 150 // Max PWM for motor 2
#define MOTOR2_ACCURACY 10 // Accuracy for motor 2
DCMotorServo servo2(lmdMotor2Write, lmdMotor2Brake, encoder2ReadFunc, encoder2WriteFunc);

// Physical parameters for motor1 rotational and speed control.
#define MOTOR1_PPR 12
#define MOTOR1_GEAR_RATIO 19
#define MOTOR1_EMPIRICAL_FUDGE_FACTOR 0.875
#define MOTOR1_ENCODER_RESOLUTION (MOTOR1_PPR * MOTOR1_GEAR_RATIO)
#define MOTOR1_CPR (MOTOR1_ENCODER_RESOLUTION * 4 * MOTOR1_EMPIRICAL_FUDGE_FACTOR)

#define MOTOR1_SPEED_INTERVAL 5 // ms

// Create first instance of the DCMotorTacho class.
DCMotorTacho tacho1(&servo1, MOTOR1_CPR, MOTOR1_SPEED_INTERVAL);

// Physical parameters for motor2 rotational and speed control.
#define MOTOR2_PPR 12
#define MOTOR2_GEAR_RATIO 19
#define MOTOR2_EMPIRICAL_FUDGE_FACTOR 0.875
#define MOTOR2_ENCODER_RESOLUTION (MOTOR2_PPR * MOTOR2_GEAR_RATIO)
#define MOTOR2_CPR (MOTOR2_ENCODER_RESOLUTION * 4 * MOTOR2_EMPIRICAL_FUDGE_FACTOR)

#define MOTOR2_SPEED_INTERVAL 5 // ms

// Create first instance of the DCMotorTacho class.
DCMotorTacho tacho2(&servo2, MOTOR2_CPR, MOTOR2_SPEED_INTERVAL);

float motor1OuterKp = 0.15, motor1OuterKi = 0.01, motor1OuterKd = 0.01;
float motor1InnerKp = 0.15, motor1InnerKi = 0.01, motor1InnerKd = 0.01;
float motor2OuterKp = 0.15, motor2OuterKi = 0.01, motor2OuterKd = 0.01;
float motor2InnerKp = 0.15, motor2InnerKi = 0.01, motor2InnerKd = 0.01;

struct DCMT_SLICE
{
    ControlModes mode = OPEN_LOOP;    // current mode of operation
    float motor1PWM = 0;              // motor 1 PWM value
    float motor2PWM = 0;              // motor 2 PWM value
    float motor1PositionSetpoint = 0; // motor 1 position setpoint
    float motor2PositionSetpoint = 0; // motor 2 position setpoint
    float motor1Position = 0;         // motor 1 position
    float motor2Position = 0;         // motor 2 position
    float motor1SpeedSetpoint = 0;    // motor 1 speed setpoint
    float motor2SpeedSetpoint = 0;    // motor 2 speed setpoint
    float motor1Speed = 0;            // motor 1 speed
    float motor2Speed = 0;            // motor 2 speed
    bool motor1Brake = false;         // motor 1 brake status
    bool motor2Brake = false;         // motor 2 brake status
    bool eStop = false;               // emergency stop flag
} slice;

struct Timing
{
    long lastSerialPrint;
} timing = {0};

void setup()
{
    // the general slice setup
    setupSlice();

    // the DCMT specific setup
    setupDCMT();

    // small delay before entering loop
    delay(1000);
}

void setupSlice()
{
    // initialize serial communication
    Serial.begin(115200);

    // Initialize CRUMBS communication
    crumbsSlice.begin();

    crumbsSlice.onRequest(handleRequest); // Register callback for data requests
    crumbsSlice.onReceive(handleMessage); // Register callback for received messages

    // initialize the LED
    FastLED.addLeds<NEOPIXEL, LED_PIN>(&led, 1);
    FastLED.setBrightness(50); // Set brightness to 50%
    led = CRGB::Blue;          // Set LED to blue
    FastLED.show();

    // initialize the estop
    pinMode(ESTOP, INPUT);
    attachInterrupt(digitalPinToInterrupt(ESTOP), estopISR, CHANGE);

    SLICE_DEBUG_PRINTLN(F("DCMT SLICE INITIALIZED"));
    SLICE_DEBUG_PRINTLN(F("VERSION: " VERSION));
}

void setupDCMT()
{
    // initialize the motor drivers
    motor1Driver.begin();
    motor2Driver.begin();

    // set the outer (position) loop PID controllers
    servo1.setPIDTunings(motor1OuterKp, motor1OuterKi, motor1OuterKd);
    servo2.setPIDTunings(motor2OuterKp, motor2OuterKi, motor2OuterKd);

    // set pwm skip
    servo1.setPWMSkip(MOTOR1_PWM_SKIP);
    servo2.setPWMSkip(MOTOR2_PWM_SKIP);

    // set max pwm
    servo1.setMaxPWM(MOTOR1_PWM_MAX);
    servo2.setMaxPWM(MOTOR2_PWM_MAX);

    // set the accuracy
    servo1.setAccuracy(MOTOR1_ACCURACY);
    servo2.setAccuracy(MOTOR2_ACCURACY);

    // set tacho speed to zero
    tacho1.setSpeedRPM(0);
    tacho2.setSpeedRPM(0);

    // set the inner (speed) loop PID controllers
    tacho1.setPIDTunings(motor1InnerKp, motor1InnerKi, motor1InnerKd);
    tacho2.setPIDTunings(motor2InnerKp, motor2InnerKi, motor2InnerKd);
}

#define SLICE_PRINT_SERIAL 1 // set to 1 to enable serial printing for debugging

void loop()
{
    // poll the emergency stop
    pollEStop();

    // update the motor control logic
    motorControlLogic();

    // serial commands input
    serialCommands();

    // serial print output
    printSerialOutput();
}

void pollEStop()
{
    if (estopTriggered)
    {
        // Update LED to indicate emergency stop
        led = CRGB::Red;
        FastLED.show();
        processEStop();
        estopTriggered = false; // Reset flag after handling
    }
    else
    {
        // Update LED to indicate normal operation
        led = CRGB::Green;
        FastLED.show();
    }
}

void estopISR()
{
    estopTriggered = true;
}

void processEStop()
{
    // Read the current state of the estop pin if needed for debouncing/validation
    if (digitalRead(ESTOP) == HIGH)
    {
        // Disable the system if the estop is pressed
        led = CRGB::Red;
        FastLED.show();
        if (slice.mode == CLOSED_LOOP_POSITION)
        {
            servo1.stop(); // Stop servo 1
            servo1.stop(); // Stop servo 2
        }
        else if (slice.mode == CLOSED_LOOP_SPEED)
        {
            tacho1.stop(); // Stop tacho 1
            tacho2.stop(); // Stop tacho 2
        }

        motor1Driver.brake(); // Brake motor 1
        motor2Driver.brake(); // Brake motor 2

        // Set the emergency stop flag in the system
        slice.eStop = true;
        SLICE_DEBUG_PRINTLN("ESTOP PRESSED!");
    }
    else
    {
        // Re-enable the system if the estop is released
        led = CRGB::Green;
        FastLED.show();
        slice.eStop = false;
        SLICE_DEBUG_PRINTLN("ESTOP RELEASED!");
    }
}

void motorControlLogic()
{
    if (slice.motor1Brake || slice.motor2Brake) // Process brakes
    {
        // Handle motor 1 brake
        if (slice.motor1Brake)
        {
            slice.motor1PWM = 0;
            motor1Driver.write(0);
            motor1Driver.brake();
        }
        // Handle motor 2 brake
        if (slice.motor2Brake)
        {
            slice.motor2PWM = 0;
            motor2Driver.write(0);
            motor2Driver.brake();
        }
    }
    else if (!slice.eStop && slice.mode == OPEN_LOOP) // Process open loop
    {
        // Update the PWM values for the motors
        motor1Driver.write(slice.motor1PWM);
        motor2Driver.write(slice.motor2PWM);
    }
    else if (!slice.eStop && slice.mode == CLOSED_LOOP_POSITION) // Process closed loop position
    {
        // Update the position setpoints for the motors
        servo1.moveTo(slice.motor1PositionSetpoint);
        servo2.moveTo(slice.motor2PositionSetpoint);       // need if statement to check change instead!!!!
        servo1.run();                                      // Run the servo 1 control loop
        servo2.run();                                      // Run the servo 2 control loop
        slice.motor1Position = servo1.getActualPosition(); // Update the current position from servo 1
        slice.motor2Position = servo2.getActualPosition(); // Update the current position from servo 2
    }
    else if (!slice.eStop && slice.mode == CLOSED_LOOP_SPEED) // Process closed loop speed
    {
        // Update the speed setpoints for the motors
        tacho1.setSpeedRPM(slice.motor1SpeedSetpoint);
        tacho2.setSpeedRPM(slice.motor2SpeedSetpoint);
        tacho1.run();                                     // Run the tacho 1 control loop
        tacho2.run();                                     // Run the tacho 2 control loop
        slice.motor1Speed = tacho1.getMeasuredSpeedRPM(); // Update the current speed from tacho 1
        slice.motor2Speed = tacho2.getMeasuredSpeedRPM(); // Update the current speed from tacho 2
    }
    else // unknown mode
    {
        // soft stop by setting brakes
        slice.motor1Brake = true;
        slice.motor2Brake = true;
        SLICE_DEBUG_PRINTLN(F("ERROR INVALID OPERATION MODE, ENTERED ERROR OR UNKNOWN STATE!"));
    }
}

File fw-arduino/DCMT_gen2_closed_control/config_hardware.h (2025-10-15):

#ifndef HARDWARE_CONFIG_H
#define HARDWARE_CONFIG_H

// ----- General BREAD -----
#define ESTOP 2
#define LED_PIN 5

// ----- DCMT Specific -----

// Timing constants
#define SERIAL_UPDATE_TIME_MS 1000

// Control modes
enum ControlModes
{
    CLOSED_LOOP_POSITION,
    CLOSED_LOOP_SPEED,
    OPEN_LOOP
};

// ----- Motor1 Definitions -----
#define MOTOR1_PWM_PIN 6
#define MOTOR1_DIR_PIN 7
#define MOTOR1_BRAKE_PIN 8
#define MOTOR1_THERMAL_PIN 9
#define MOTOR1_ENCODER_PIN1 A2
#define MOTOR1_ENCODER_PIN2 A3
#define MOTOR1_CSENSE_PIN A6

// ----- Motor2 Definitions -----
#define MOTOR2_PWM_PIN 11
#define MOTOR2_DIR_PIN 10
#define MOTOR2_BRAKE_PIN 12
#define MOTOR2_THERMAL_PIN 13
#define MOTOR2_ENCODER_PIN1 A0
#define MOTOR2_ENCODER_PIN2 A1
#define MOTOR2_CSENSE_PIN A7

#endif // HARDWARE_CONFIG_H

#define DIR1 5
#define MC1 6
#define BR1 7
#define DIR2 9
#define MC2 10
#define BR2 11

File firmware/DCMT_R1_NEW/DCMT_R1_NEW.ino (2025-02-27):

#include <Wire.h>
// #include <SPI.h>

#define I2C_ADR 14 // Set this however you want

#define DIR1 6
#define MC1 7
#define BR1 8
// #define THRM1 9
#define DIR2 10
#define MC2 11
#define BR2 12
// #define THRM2 13

// #define B2 A0
// #define A2 A1
// #define B1 A2
// #define A1 A3

bool dir1 = 1; // start with forward
bool dir2 = 1;
bool br1 = 1; // start with brake on
bool br2 = 1;

int pwm1, pwm2 = 0; // start with 0 speed

typedef union // Define a float that can be broken up and sent via I2C
{
    float number;
    uint8_t bytes[4];
} FLOATUNION_t;

FLOATUNION_t RX;

byte commandSelect[3];
int8_t speedSelect;
int8_t motor1Speed;
int8_t motor2Speed;
byte motorSelect;
bool changeParam = false;

#define SERIAL_UPDATE_TIME_MS 1000

long lastSerialPrint = 0;

enum Mode
{
    CONTROL,
    WRITE
};

Mode currentMode = CONTROL;

void setup()
{
    pinMode(MC1, OUTPUT);
    pinMode(MC2, OUTPUT);
    pinMode(DIR1, OUTPUT);
    pinMode(DIR2, OUTPUT);
    pinMode(BR1, OUTPUT);
    pinMode(BR2, OUTPUT);

    Serial.begin(115200); // updated baud rate
    Wire.begin(I2C_ADR);
    Wire.onReceive(receiveEvent);
    Wire.onRequest(requestEvent);
}

void loop()
{
    serialCommandHandler();

    if (changeParam)
    {
        switch (motorSelect)
        {
        case 1: // Motor 1 edit
            if (speedSelect == 0)
            {
                br1 = 1;
                pwm1 = 0;
                Serial.println("Motor 1 brake");
            }
            else if (speedSelect < 0 && speedSelect >= -100)
            {
                br1 = 0;
                dir1 = 0;
                speedSelect *= -1;
                pwm1 = map(speedSelect, 0, 100, 0, 255);
                Serial.print("Motor 1 back ");
                Serial.println(pwm1);
            }
            else if (speedSelect > 0 && speedSelect <= 100)
            {
                br1 = 0;
                dir1 = 1;
                pwm1 = map(speedSelect, 0, 100, 0, 255);
                Serial.print("Motor 1 forward ");
                Serial.println(pwm1);
            }
            else
            {
                Serial.println("Invalid Entry, nothing will be changed");
            }
            break;

        case 2: // motor 2 edit
            if (speedSelect == 0)
            {
                br2 = 1;
                pwm2 = 0;
                Serial.println("Motor 2 brake");
            }
            else if (speedSelect < 0 && speedSelect >= -100)
            {
                br2 = 0;
                dir2 = 0;
                speedSelect *= -1;
                pwm2 = map(speedSelect, 0, 100, 0, 255);
                Serial.print("Motor 2 back ");
                Serial.println(pwm2);
            }
            else if (speedSelect > 0 && speedSelect <= 100)
            {
                br2 = 0;
                dir2 = 1;
                pwm2 = map(speedSelect, 0, 100, 0, 255);
                Serial.print("Motor 2 forward ");
                Serial.println(pwm2);
            }
            else
            {
                Serial.println("Invalid Entry, nothing will be changed");
            }
            break;

        default:
            Serial.println("oopsie poopsie, that's not a command, silly");
            break;
        }
        changeParam = false;
    }

    digitalWrite(DIR1, dir1);
    analogWrite(MC1, pwm1);
    digitalWrite(BR1, br1);
    digitalWrite(DIR2, dir2);
    analogWrite(MC2, pwm2);
    digitalWrite(BR2, br2);

    printOutput();
}

void printOutput()
{
    if (millis() - lastSerialPrint >= SERIAL_UPDATE_TIME_MS)
    {
        Serial.print("SpeedSelect: ");
        Serial.print(speedSelect);
        Serial.print(", MotorSelect: ");
        Serial.print(motorSelect);
        Serial.print(" || ");
        Serial.print("Speed1: ");
        Serial.print(motor1Speed);
        Serial.print(", PWM1: ");
        Serial.print(pwm1);
        Serial.print(", Dir1: ");
        Serial.print(dir1);
        Serial.print(", Brake1: ");
        Serial.print(br1);
        Serial.print(", Speed2: ");
        Serial.print(motor2Speed);
        Serial.print(", PWM2: ");
        Serial.print(pwm2);
        Serial.print(", Dir2: ");
        Serial.print(dir2);
        Serial.print(", Brake2: ");
        Serial.println(br2);

        lastSerialPrint = millis();
    }
}

void serialCommandHandler()
{
    if (Serial.available())
    {
        String command = Serial.readStringUntil('\n');
        command.trim();
        char cmdType = command.charAt(0);

        if (cmdType == 'M')
        { // Mode switch command: "M,0" for CONTROL, "M,1" for WRITE
            int mode = command.substring(2).toInt();
            if (mode == 0)
            {
                currentMode = CONTROL;
                Serial.println("Switched to CONTROL mode");
            }
            else if (mode == 1)
            {
                currentMode = WRITE;
                Serial.println("Switched to WRITE mode");
            }
        }
        else if (cmdType == 'W')
        { // Motor update command in the format: "W,<motorSelect>,<speedSelect>"
            int firstComma = command.indexOf(',');
            int secondComma = command.indexOf(',', firstComma + 1);
            if (firstComma != -1 && secondComma != -1)
            {
                motorSelect = command.substring(firstComma + 1, secondComma).toInt();
                speedSelect = command.substring(secondComma + 1).toInt();
                changeParam = true;
                Serial.print("Serial update: motorSelect = ");
                Serial.print(motorSelect);
                Serial.print(", speedSelect = ");
                Serial.println(speedSelect);
            }
            else
            {
                Serial.println("Invalid command format for motor update.");
            }
        }
        else
        {
            Serial.println("Invalid serial command!");
        }
    }
}

void requestEvent()
{
    Serial.print("Sending: ");
    Serial.print(motor1Speed);
    Serial.print(", ");
    Serial.println(motor2Speed);

    Wire.write(motor1Speed);
    Wire.write(motor2Speed);
}

void receiveEvent(int howMany)
{
    int i = 0;
    while (Wire.available())
    {
        commandSelect[i] = Wire.read();
        Serial.print(i);
        Serial.print("-> ");
        Serial.print(commandSelect[i]);
        Serial.print(", ");
        i++;
    }
    Serial.println();
    motorSelect = commandSelect[0];
    speedSelect = commandSelect[1];

    switch (motorSelect)
    {
    case 1:
        motor1Speed = speedSelect;
        break;
    case 2:
        motor2Speed = speedSelect;
        break;
    }

    changeParam = true;
}

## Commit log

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2025-05-06 fixed to use elec cap, fill zones instead of traces, tab down for thermal
    [BOM_DCMT_R1.ods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]
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2025-09-06 fix(ci): switch to mikefarah/yq container in pages job to avoid apt-get permission errors
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2025-09-06 swap order to stage files before rebase pull to avoid unstages changes error
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2026-03-19 fix: function declaration ordering for servo1/2
    [main.cpp]
2026-03-19 remove duplicate (drift prone) version in favour of the canonical version defined in contract
    [main.cpp]
2026-03-19 inset encoder range by 1 to avoid falsely reporting sentinel value
    [main.cpp]
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2026-05-12 fix(fw): protect shared state with interrupt guards
    Use snapshot-in/commit-out pattern in motorControlLogic to prevent
    torn reads between I2C ISR (reply_get_state) and main loop writes.
    Add noInterrupts/interrupts guards around processEStop writes.
    [main.cpp]
2026-05-12 fix(fw): replace String with static buffer in serial commands
    Eliminates all heap allocations from the serial command parser.
    Uses a 64-byte static char buffer and C string functions (atol,
    strtod, strcmp_P) to prevent heap fragmentation on long-running
    ATmega328 devices.
2026-05-12 fix(fw): portability fixes for megaAVR targets
    Simplify WDT include guard, fix Timing.lastSerialPrint to unsigned
    long to match millis() return type and prevent signed overflow.
    [globals.h, main.cpp]
2026-05-17 fix: race commit with local motor pwm
    [main.cpp]
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2026-07-14 fix(firmware): shrink motorControlLogic interrupt-masked snapshot (#4)
    The 2026-05-12 shared-state hardening copied the whole ~72-byte
    DCMT_SLICE with interrupts masked every loop iteration (~20-36 us).
    That window delays TWI ISR entry at the SLA+R boundary; the AVR then
    clock-stretches, which the Raspberry Pi's I2C controller mishandles,
    corrupting ~1-47% of CRUMBS state queries (all-0xFF non-responses or
    CRC-corrupt replies, rate aliasing against poll spacing).
    Snapshot only the scalar control inputs (~15 bytes) in one short cli
    window; fetch PID tunings in a separate short window only when a
    closed-loop mode is active. A torn view across the two windows
    self-corrects on the next iteratio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
    [main.cpp]
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2026-07-18 fix: stamp watchdog liveness in every reply builder (#9)
    The armed watchdog tripped on a healthy idle bench: the controller's
    1 Hz GET_STATE poll never fed it. SET_REPLY staging frames are not
    dispatched to on_message (CRUMBS excludes them), and only the
    GET_WATCHDOG reply builder stamped wdLastRxMs — so with a 5 s timeout
    the watchdog expired 5 s after arming despite continuous polling, and
    any MANUAL command would have auto-braked 5 s later.
    Stamp wdLastRxMs in all reply builders (version, GET_STATE, GET_CAPS,
    GET_WATCHDOG) as the design in #6 specified: any reply build proves a
    live master. Found live on the bench minutes after first arming
    (anolishq/anolis-provider-bread#113 rollout).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
2026-07-19 fix: stop brake-pin toggling in safe-state hold loops (#10)
    * fix: stop brake-pin toggling in safe-state hold loops
    The watchdog-trip hold, e-stop hold, and manual-brake branches called
    write(0) before brake() every loop iteration; LMD18200::write()
    releases the brake pin before driving, so the brake pin and PWM
    toggled at loop frequency — audible as a motor squeal (heard live
    during the first watchdog-trip hold; cleared the moment the trip
    cleared) and needless switching stress on the driver.
    Call brake() alone in those branches, and take LMD18200 0.1.4 whose
    brake()/releaseBrake() are state-tracked and idempotent, so repeated
    per-iteration holds perform no pin writes at all. The lib is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
    [main.cpp]
2026-07-22 fix: hold watchdog safe-state in motorControlLogic, not just watchdogLogic (#11) (#12)
    On a command-watchdog trip while a motor is driven, motorControlLogic()
    released the brake that watchdogLogic() engaged — every loop iteration —
    because it guarded only eStop, not wdTripped. It fell through to the
    OPEN_LOOP motorNDriver.write(0) (or CLOSED_LOOP servo.run()), and
    LMD18200::write() calls releaseBrake() first, so brake+PWM toggled at
    loop frequency: an audible driver whine and a soft oscillating brake
    instead of a clean hard-brake. The motor still stopped, so the safety
    net functioned, but degraded. Reproduced on hardware (spinning impeller,
    software SIGKILLed >5s).
    #10 removed write(0)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
    [main.cpp]
2026-09-09 fix(firmware): compile the status LED out on gen1, where it shares MOTOR1_DIR (#16)
    G1 boards have no status LED -- absent from the design, not merely
    unpopulated. Zero WS2812 parts and no /LED net in either G1 board file,
    and no G1 board ever carried an LED of any kind.
    LED_PIN 5 lives in the shared "General BREAD" block that every slice
    inherits (Slice_RLHT carries the identical line), so it was defined on
    gen1 regardless. Because gen1 also maps MOTOR1_DIR to pin 5 -- D5 carries
    /DIR2 straight into an LMD18200's DIRECTION input -- the LED code was
    bit-banging NeoPixel timing into a motor driver's direction line to drive
    a part that does not exist.
    Motor 1 is the sample pump on dcmt0 and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
    [config_hardware.h, globals.h, main.cpp]
2026-09-10 fix(firmware): put gen2 motor 2 PWM on a timer pin, and fail the build otherwise (#21)
    Matches the G2 D10<->D11 trace rework, now applied to all six G2 boards.
    As fabricated, G2 routed /MC2 (PWM) to D11 and /DIR2 to D10. D11 has a
    hardware timer on the ATmega328P but not on the ATmega4809, so on a Nano
    Every analogWrite() degraded to a digital write at a threshold of 128:
    motor 2 was off below 128 and at full output at or above it, with no
    proportional control and no error. That is the MCU used for encoder
    closed-loop work, so the degradation landed where it hurt most.
    The rework swaps them so PWM is on D10, a timer pin on both MCUs.
    DIRECTION only needs a digital pin, so nothing is lost o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
    [config_hardware.h]
2026-09-10 docs: record the board generations, reworks and wiring conventions (#20)
    Every open hardware issue on this repo traced back to the absence of this
    page. Two real defects were caught by hand at a bench months apart and
    neither was written down, so both were later rediscovered from the KiCad
    files alone -- and one was initially misdiagnosed, because the board in
    hardware/ is not the board in service.
    Records, per generation:
    - Which board files are which. G1 lives under archive/hw_archive/ and runs
    on the reference rig; hardware/ holds G3, which is undeployed and has no
    firmware profile.
    - Full Nano pin maps for all three, so a pin-assignment claim can be
    checked against a table instea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
2026-09-10 chore(archive): upgrade the archived board files to the KiCad 10 format (#22)
    The archived projects were last saved by KiCad 5.1 (`2021-06-08`), 6.x
    (`2023-12-13`) and 9.0 (`recent_finn`), and no longer load cleanly in
    the
    current toolchain. All three are now saved by KiCad 10.0.6, so they can
    be
    opened, netlisted and DRC-checked without a per-file conversion step.
    **The upgrade changes format only.** Verified per board by normalizing
    both
    revisions out of the s-expressions and diffing:
    | board | previous format | pad → net | copper (tracks + arcs + vias) |
    |---|---|---|---|
    | `2021-06-08` | KiCad 5.1 | identical, 112 pads | identical, 198 items
    |
    | `2023-12-13` | KiCad 6.x | identical,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
    [BREAD_Slice.kicad_pcb, BREAD_Slice.kicad_sch]
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2026-09-10 fix(ci): drop the stray hardware/.history gitlink (#25)
    **Holding this for review — not merging it without a word from you.**
    `hardware/.history` is recorded in the index as a **gitlink** (mode
    `160000`,
    `9610d72`) with no `.gitmodules` entry. It was added in `a7298bb`.
    `actions/checkout` fails on it during submodule init:
    ```
    fatal: No url found for submodule path 'hardware/.history' in .gitmodules
    ##[error]The process '/usr/bin/git' failed with exit code 128
    ```
    All three KiBot jobs in the Docs Pipeline — Fab, ERC and DRC — fail at
    checkout
    before running, so `gen-kibot-index` and `deploy-pages` skip and the
    published
    docs have not been rebuilt. Every run of that workflow has fail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
2026-09-10 chore: mechanical remediation (KiCad 10, DRC gate, Makefile, gitignore) (#2)
    Fleet-wide mechanical pass. **No library or design changes** — not a
    single part is altered.
    Each step is a separate commit so any one can be reverted independently.
    Please **merge, do not squash**, so the per-step history survives.
    ## Commits
    - `b052476` chore: gitignore KiCad 10 local history
    - `a2e85d5` fix(hw): fail DRC on schematic/PCB footprint mismatch
    - `6deebd2` fix(hw): un-swap the ERC and DRC Makefile targets
    ## What each one fixes
    | | |
    | --- | --- |
    | **KiCad 10** | Via `kicad-cli sch upgrade` / `pcb upgrade`. Verified
    lossless on a real board: identical netlist, footprint positions and
    routing.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
2026-10-05 docs: drop the TODO files now that work is tracked in issues (#34)
    Removes `TODO.md` and `docs/TODO.md`. Work is tracked in issues now.
    - `TODO.md` closed-loop validation: moved to #32. Its build-validation
    item is dropped, because Firmware Build CI compiles all four envs on
    every firmware change.
    - `docs/TODO.md` grounding and return paths: moved to #33.
    `docs/_config.yml` still lists `TODO.md` under `exclude:`. The entry
    comes from the shared docs template and is harmless without the file.
2026-10-13 feat(firmware): codec adoption and a latched watchdog trip that resumes nothing (#31)
    Closes #28, closes #26. Supersedes #14 (the same latch, plus the split
    it was waiting on).
    `platformio.ini` pins `bread-crumbs-contracts @ ^0.6.0` and `CRUMBS @
    ^0.14.0`. 0.6.0 (feastorg/bread-crumbs-contracts#29 + #30) is now on the
    PlatformIO registry; the Firmware Build failures from 2026-10-05 were
    that package not resolving, and the re-run on this head passes all four
    board environments. This branch supersedes #14.
    ## Codec (#28)
    The SET handlers unpack with the contracts' generated `dcmt_*_unpack()`.
    GET_STATE fills a `dcmt_state_t` and packs it with `dcmt_state_pack()`.
    Handler behaviour is unchan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
2026-10-14 fix(firmware): require DCMT_HW_GEN instead of defaulting to gen1 (#41)
    `firmware/include/config.h` defined `DCMT_HW_GEN` as 1 when the build
    flag was absent. `config_hardware.h` includes `config.h` first, so its
    `#error "Unsupported DCMT_HW_GEN value"` guards could only reject an
    out-of-range value, never a missing one. A gen2 board built outside the
    `gen*` PlatformIO envs got the gen1 motor pin map with no diagnostic.
    - `config.h`: a missing `DCMT_HW_GEN` is now an `#error` that points to
    the `gen*` envs in `firmware/platformio.ini`.
    - `firmware-build.yml`: on the `gen1_nano` leg, a step preprocesses
    `config.h` without the flag and fails unless `cc -E` exits non-zero
    with that error.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
2026-10-19 fix(firmware): refuse the SETs the firmware drops (#44)
    Every SET the firmware does not act on in full is now refused with
    `crumbs_refuse()` and a reason from bread-crumbs-contracts
    `bread_refuse.h`, so GET_ACK reports it refused instead of applied.
    Before this, no handler called `crumbs_refuse()`, and
    `on_crumbs_message`, registered as `on_message` for the watchdog stamp,
    made CRUMBS count every decoded frame as applied. The bench measurement
    in #43 (dcmt0 at 0x14, gen1_nano, CRUMBS 0.16.0 `send_confirmed`) read
    applied for a SPEED SET_PID with the speed loop not built, a SET_PID
    with loop `0x07`, a 12-byte SET_PID and opcode `0x3F`.
    | Reason | Where |
    | `MALFORMED` | any `*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
2026-10-20 fix(firmware): assert the e-stop on the first LOW sample (#47)
    `pollEStop()` restarted its 25 ms debounce timer on every edge of the
    e-stop line, so edges less than 25 ms apart kept `processEStop()` from
    running for as long as they lasted, whatever the line's level (#39).
    - `pollEStop()` now samples the line on every loop pass. The first LOW
    sample asserts the e-stop; release needs 25 ms with no LOW sample. A
    line that keeps chattering after a release stays stopped.
    - `processEStop(bool pressed)` takes the debounced state instead of
    re-reading a pin that may have bounced since. The CHANGE interrupt,
    which only set a flag, is removed along with `estopTriggered` and
    `estopISR()`.
    - `setup()`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
2026-10-20 feat(firmware): hold the e-stop like a watchdog trip (#48)
    Implements `DCMT_CAP_ESTOP_HOLD` as bread-crumbs-contracts defines it,
    with the text from feastorg/bread-crumbs-contracts#57. It builds on the
    e-stop sampling from #47.
    **The problem** (#46, #30). The press braked the motors and zeroed PWM
    and speed setpoints, but left the brake flags and position setpoints
    alone. Every motion command sent during the hold, over I2C or serial,
    was stored, so releasing the line ran it. In position mode the motor
    drove back toward its old target: the #30 host run shows 194 of 200
    ticks at PWM 150.
    **The change.** The e-stop now holds the way the watchdog trip already
    does:
    - **Press:** both brake fla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
2026-10-20 fix(firmware): refuse GET opcodes as commands and reject other families' frames (#50)
    Fixes the two gaps #45 describes.
    **GET opcodes sent as command frames** (#45). `is_defined_op()` was
    built from `DCMT_OPS` and `BREAD_COMMON_OPS`, which also hold GET_STATE
    (0x80), GET_WATCHDOG (0x7D) and GET_CAPS (0x7F). Those are queries
    answered through SET_REPLY, so as a command frame nothing handled them,
    and `on_message` taking the frame made GET_ACK report APPLIED.
    `is_command_op()` now lists the seven opcodes `setupSlice()` registers a
    command handler for, so the GET opcodes are refused with
    `BREAD_REFUSE_UNKNOWN_OP`. A query added to the contract later can't
    read APPLIED either.
    **Frames typed f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
2026-10-20 build(pio): pin the atmelavr and atmelmegaavr platforms (#52)
    `platform = atmelavr` and `platform = atmelmegaavr` named no version, so
    every clean build and CI run took the newest platform release. The
    compiler and Arduino core could change between two builds of the same
    commit with no change in the repo.
    This pins them to the versions builds already resolve:
    - `platformio/atmelavr @ 5.3.0`
    - `platformio/atmelmegaavr @ 1.10.0`
    Both are the latest in the PlatformIO registry
    (`api.registry.platformio.org/v3/packages/platformio/platform/<name>`:
    atmelavr 5.3.0 released 2026-06-23, atmelmegaavr 1.10.0 released
    2026-04-28). The CI run on feastorg/Slice_RLHT#41 (run 39447685178)
    logged `Atmel A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
2026-10-20 fix(firmware): keep the status LED blue through the boot wait (#56)
    The gen2 status LED never shows blue at boot. On the bench, a gen2 DCMT
    Nano went straight to green at power-up and on reset.
    **Cause.** Since the e-stop sampling change (#47), the 1 s boot wait in
    `setup()` calls `pollEStop()` instead of `delay(1000)`. `pollEStop()`
    also wrote the status LED, so its first pass, microseconds after the
    boot blue, wrote green, or red with the e-stop held. Before #47, blue
    held for the `delay(1000)`.
    **Fix.** The LED update moves out of `pollEStop()` into
    `updateStatusLed()`, called from `loop()` only, right after
    `pollEStop()`:
    - blue holds through the boot wait;
    - the first loop pass shows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
2026-10-21 fix(firmware): clear the open-loop PWM when serial MODE= leaves open loop (#70)
    Closes #36.
    I2C `SET_MODE` zeroes both motor PWMs when the new mode isn't open loop
    (`dcmt_handlers.cpp`), but serial `MODE=` only set the mode. `MODE=` now
    sets the mode and clears both PWMs in one masked window, as the handler
    does. Staying in open loop keeps the PWM, as before.
    ## Test
    `test_mode_pwm` (new) drives `loop()` with serial lines and CRUMBS
    frames, and checks GET_STATE and the motor driver stub.
    Before the fix, in all four envs:
    FAIL serial MODE=POS: GET_STATE reads m1_pwm 0 and m2_pwm 0
    FAIL serial MODE=OPEN after POS: motor 1 is not driven at the old PWM
    FAIL serial MODE=OPEN after POS: m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
2026-10-21 fix(firmware): report the driven PWM in GET_STATE (#71)
    Closes #61.
    The contract describes GET_STATE `m1_pwm`/`m2_pwm` as the current PWM
    output (`dcmt_ops.h`). They reported `slice.motorNPWM`, which is the
    open-loop request. So in position and speed mode they read 0 while the
    servo drove the motors at up to ±150.
    ## Change
    - Every driver write and brake now goes through
    `motor1_write`/`motor1_brake` (and motor 2's), the wrappers DCMotorServo
    already called. Before, `setupDCMT`, the e-stop, the watchdog trip, the
    hold, open loop and the closed-loop brake branches called the driver
    directly.
    - Each wrapper records the clamped PWM it wrote, or 0 when braking, in
    `motorNAppliedPWM`, under a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
2026-10-21 fix(firmware): mask serial PWM and PID writes against the I2C handlers (#72)
    Closes #37.
    Four serial commands write `slice` fields that the I2C handlers also
    write from the TWI interrupt, and they wrote with interrupts enabled:
    - `M1PWM=` and `M2PWM=`: an int16 each;
    - `PIDPOS=` and `PIDSPEED=`: two 12-byte gain structs each.
    A `SET_OPEN_LOOP` or `SET_PID` landing mid-write could leave a PWM with
    one byte from each command, or a motor with gains from two commands.
    Each write now happens in a masked window, as the setpoint and brake
    writes already did.
    `M1PWM=`/`M2PWM=` now also check the mode inside the same window.
    Before, a `SET_MODE(POS)` landing between the check and the write zeroed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
2026-10-21 fix(firmware): handle one serial line per loop pass (#73)
    Closes #49.
    `serialCommands()` handled every complete line in the receive buffer in
    one call, and each reply blocks once the 64-byte transmit buffer fills.
    The e-stop is sampled once per `loop()` pass, so a burst of serial input
    held the e-stop sample for as long as the burst took to answer. A
    continuous stream could hold it until the 1 s hardware watchdog reset
    the board.
    It now returns after one complete line, and the rest of the buffer waits
    for the next pass.
    `test_serial_burst` (new):
    1. Five lines arrive at once. One pass answers one line and the other
    four stay buffered.
    2. Four more passes answer the remaining lin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
2026-10-23 docs(bench): add the 2026-10-22 record (#75)
    Bench record for 2026-10-22, with a row in `docs/bench/README.md`.
    - `4254ea5` on gen2 Nano and Nano Every: boot LED (#56), applied PWM in
    GET_STATE (#61), watchdog trip and e-stop hold pass. The serial blocks
    (#49, #36, #37) were not run.
    - Against DCMotorServo `cc8bad6` and lmd18200 `b11192a`:
    CameronBrooks11/DCMotorServo#12, CameronBrooks11/DCMotorServo#13 (with
    #62) and CameronBrooks11/DCMotorServo#11 pass.
    - A 300-count lead cap removes the stall-release lunge; #63 takes 300.
    - CameronBrooks11/lmd18200#2: `readCurrent()` scales correctly at DC
    drive (0.322 A against 0.334 A on the meter) and reads 0.045 A at zero
    current.
    Assets: the raw co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
2026-10-23 refactor(firmware): move e-stop, watchdog and LED onto bread-slice-core (#77)
    DCMT takes its e-stop input, command watchdog and status LED from
    bread-slice-core 0.1 (feastorg/.github#4). This replaces #55.
    - `bsc::EStop` and `bsc::bootWait()` replace `pollEStop()`,
    `slice.eStop` and `estopCount`. `processEStop()` keeps DCMT's brake and
    setpoint handling and runs on the `Pressed` event.
    - `bsc::CommandWatchdog` replaces the `wd*` globals in the I2C handlers,
    serial `WDOG=`/`WDCLEAR` and `watchdogLogic()`. The trip action is
    unchanged.
    - `bsc::StatusLed` replaces FastLED on gen2. FastLED is gone from
    `platformio.ini` and `slice.yaml`.
    Behaviour changes:
    - the boot wait restamps the watchdog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
2026-10-24 docs(changelog): credit gen1's growth to the core's e-stop and watchdog (#78)
    The #77 entry read as though the LED caused gen1's growth. Gen1 has no
    LED and never includes the driver; the growth is bsc::EStop and
    bsc::CommandWatchdog keeping the pin, polarity and debounce as members
    (estopInput and commandWatchdog are 19 B, against 15 B for the globals
    they replaced).
2026-10-24 fix(firmware): parse serial numbers strictly (#79)
    Every serial number goes through bread-slice-core's `parseLong()` or
    `parseFloat()`. The whole token must parse and be in range for its
    field, or the command is refused with an `Ignored:` line and nothing
    changes.
    | Field | Range | Note |
    | --- | --- | --- |
    | `M1PWM=`, `M2PWM=` | -255 to 255 | refused where it used to clamp, as
    SET_OPEN_LOOP refuses it |
    | `M1POS=`, `M2POS=`, `M1SPEED=`, `M2SPEED=` | -32767 to 32767 | -32768
    is GET_STATE's invalid sentinel |
    | `WDOG=` | 0 to 65535 | `WDOG=0` still disarms |
    | `PIDPOS=`, `PIDSPEED=` | three fields, each 0 to 65.535 | SET_PID's
    range (u16 x1000) |
    `test_serial_numbers` has each row of #60 a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
2026-10-25 build: require bread-crumbs-contracts 0.11.0 (#82)
    0.11.0 defines the 5-byte SET_SETPOINT (#57), the watchdog lease and
    the stall faults (#64) that DCMT implements next. It is additive: no
    existing opcode or payload changes and DCMT advertises none of the new
    flags, so behaviour is unchanged. All four envs build and the host
    suite passes against it; gen1_nano is 22344 B of flash, as on 0.10.0.
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2026-10-26 refactor(firmware): refuse unhandled opcodes from the handler table (#87)
    `on_message` refused UNKNOWN_OP any opcode missing from
    `is_command_op()`, a list kept by hand beside the
    `crumbs_register_handler()` calls. It now asks CRUMBS with
    `crumbs_has_handler()` (feastorg/CRUMBS#124, released in 0.17.0). The
    registrations become the firmware's only list. `test_dispatch.cpp` keeps
    its own as the test's oracle. A command with no handler is now refused,
    where before it answered APPLIED with nothing behind it. That covers a
    failed registration, and a frame that lands between
    `crumbs_set_callbacks()` and its opcode's registration at boot. The
    second is a window a few registration calls long.
    - **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
2026-11-01 docs(bench): add the 2026-10-31 record (#95)
    Adds the 2026-10-31 bench record, on `main` at `c3e6fca`. No motor step
    was run.
    - U1, on the gen2 Nano Every: GET_STATE, GET_CAPS, GET_WATCHDOG and an
    unassigned 0x40 sent as command frames read UNKNOWN_OP (reason 7), and
    SET_MODE 0 still applies. Verifies #87.
    - B1: with the binding's retries off, 0 of 2554 GET_STATE replies failed
    on the gen2 Nano Every and 1 of 2555 on the gen2 Nano. Slice_RLHT's gen2
    Nano, on the same bus, failed 2 to 4 % (feastorg/Slice_RLHT#81).
    The record links Slice_RLHT's `replylog.py` on `main`, which arrives
    with feastorg/Slice_RLHT#82.
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
